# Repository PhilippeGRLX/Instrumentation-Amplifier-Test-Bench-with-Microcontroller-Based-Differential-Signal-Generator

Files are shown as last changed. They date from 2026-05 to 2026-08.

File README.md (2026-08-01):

# Instrumentation Amplifier Test Bench with Microcontroller-Based Differential Signal Generator

#### Implementation of an instrumentation amplififer with PWM-generated differential and common-mode noise source

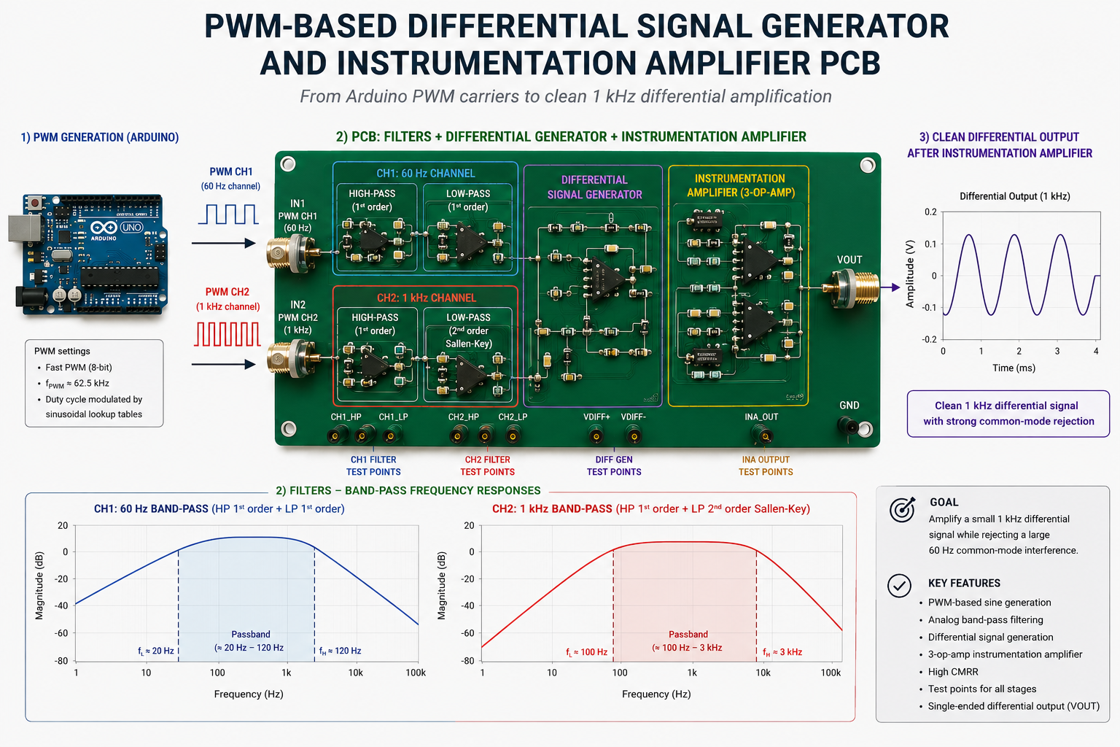
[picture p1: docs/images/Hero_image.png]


## Introduction

The aim of this repository is to help students, hobbyists and engineers build a practical understanding of instrumentation amplifiers (INAs). By exploring their ability to reject common-mode interference while preserving differential signal integrity, the reader will develop an understanding of their key role in signal acquisition and conditioning. The repository also includes a diferrential signal generator designed as a test bench for the instrumentation amplifier. Its design process is well documented for any reader interested in PWM-based signal synthesis, active analog filtering and frequency-domain analysis using oscilloscope measurements and MATLAB.

<p align="center">
<em>
This project is built around the idea that a design is only as valuable as the engineer's ability to validate it experimentally.
</em>
<br>
<sub>Inspired by a discussion with Petr Dvořák on <em>The Amp Hour</em> #669.</sub>
</p>

Throughout this project, the reader will explore:
- Microcontroller-based PWM signal synthesis (Arduino Uno),
- First and second order active filters design for PWM-based sinusoidal signal synthesis,
- Theoretical Frequency domain analysis with Matlab simulations,
- Experimental Frequency domain analysis of the synthesised signals and hardware (oscilloscope),
- Experimental instrumentation amplifier validation.

Project workflow:
1. Generate two PWM-modulated sinusoidal signals using an Arduino.
2. Reconstruct the sinusoidal envelopes through active analog filters.
3. Combine both signals into differential and common-mode components.
4. Characterize the generated signals using oscilloscope measurements and MATLAB.
5. Evaluate the instrumentation amplifier's ability to reject common-mode interference while preserving the differential signal.

> [!IMPORTANT]
> **Why generate sinusoidal test signals?**
>The instrumentation amplifier can be though of as a building block of a signal acquisition circuit. Wires and PCB tracks are susceptible to ambient electromagnetic noise wich deteriorates the useful signal's integrity. The 60 Hz common mode signal used in the test bench is meant to represent the noise induced by the ambient power grid which has a sinusoidal shape. As for the usefull signal, its sinusidal shape is chosen for simplicity, but also because the signal's quality is easy to asses visualy.

> [!Note]
> While the complete PCB files are provided to allow readers to reproduce the project, the primary objective of this repository is educational. Readers are encouraged to adapt, improve, and experiment with the design rather than simply replicate it.

## Table of Contents

- [Introduction](#introduction)

- [System Overview](#system-overview)
  - [Generating Sinusoidal Signals from Filtered PWM Carriers](#generating-sinusoidal-signals-from-filtered-pwm-carriers)
  - [Analog Filter Stages](#analog-filter-stages)
    - [First-Order Active High-Pass Filter](#first-order-active-high-pass-filter)
    - [First-Order Active Low-Pass Filter](#first-order-active-low-pass-filter)
    - [Second-Order Sallen-Key Low-Pass Filter](#second-order-sallen-key-low-pass-filter)
  - [Differential Signal Generator](#differential-signal-generator)
  - [Instrumentation Amplifier](#instrumentation-amplifier)

- [CMRR and Measured Performance](#cmrr-and-measured-performance)

- [Testing the Signal](#testing-the-signal)
  - [Experimental PWM Signal Validation](#experimental-pwm-signal-validation)
  - [Viewing Filtered Sinusoidal Signals](#viewing-filtered-sinusoidal-signals)
  - [Viewing Differential Signals with Common Mode](#viewing-differential-signals-with-common-mode)
  - [Viewing Common-Mode Attenuation](#viewing-common-mode-attenuation)

- [Hardware Implementation](#hardware-implementation)
  - [Breadboard Prototype](#breadboard-prototype)
  - [PCB Design](#pcb-design)
    - [Signal Generator PCB](#signal-generator-pcb)
    - [Instrumentation Amplifier PCB](#instrumentation-amplifier-pcb)
    - [Performance](#performance)

- [Compatibility](#compatibility)
- [Safety](#safety)
- [Resources](#resources)
- [Acknowledgements](#acknowledgements)

## System overview

### Generating sinusoidal signals from filtered PWM carriers

The Arduino could generate a staircase approximation of a sinusoidal waveform directly from the lookup-table (LUT) values. However, the quantization and discrete-time updates inherent to a staircase waveform introduce additional spectral components. Since the objective is to characterize the INA, these imperfections would make it more difficult to distinguish distortion originating from the signal generator from distortion introduced by the instrumentation amplifier under test (See Figure 1).

<p align="center">
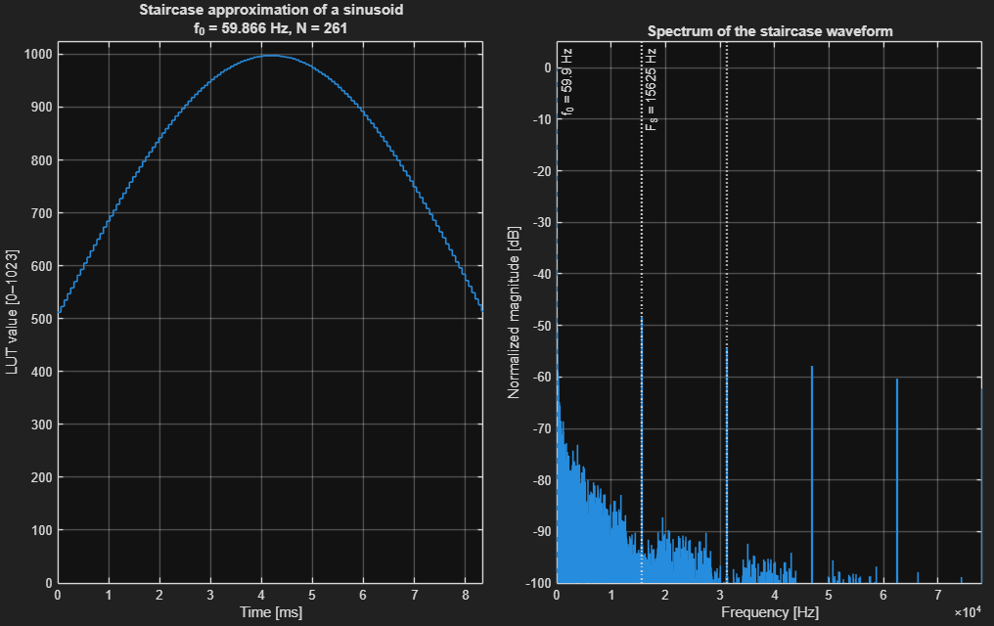
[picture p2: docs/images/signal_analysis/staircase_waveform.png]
  
</p>

<p align="center">
  <em>
    Figure 1. Staircase approximation of the 60 Hz sinusoidal signal
    generated from the lookup-table values and its normalized frequency
    spectrum (right). In addition to the desired fundamental component, the
    discrete update process produces high-frequency spectral images around
    the LUT update frequency.
  </em>
</p>

Instead, the sinusoidal lookup table is used to continuously adjust the duty cycle of a high-frequency PWM carrier. By shifting most of the unwanted spectral content around the PWM carrier frequency, analog reconstruction filters can effectively recover the low-frequency sinusoidal envelope.

The analog reconstruction filters are designed to:
- remove the DC component introduced by the PWM duty-cycle offset,
- preserve the desired sinusoidal envelope,
- attenuate the PWM carrier and its associated sidebands.

The figures below illustrate the signal generation process for the 60 Hz path.

#### Sinusoidal lookup table

The sinusoidal lookup table (LUT) defines the duty-cycle trajectory used to modulate the PWM carrier.

The LUT values are generated offline and embedded in the Arduino firmware through dedicated header files located in the firmware section of this repository. During operation, the microcontroller continuously updates the PWM duty cycle by stepping through the LUT entries.

Although Figure 2 displays a sinusoidal waveform for visualization purposes, no analog sinusoidal voltage is directly generated by the microcontroller. The only signal produced by the Arduino is a variable-duty-cycle PWM waveform whose average value follows the sinusoidal trajectory defined by the LUT.

After analog filtering, the low-frequency sinusoidal envelope is reconstructed while the high-frequency PWM carrier and its associated harmonics are attenuated.
<p align="center">
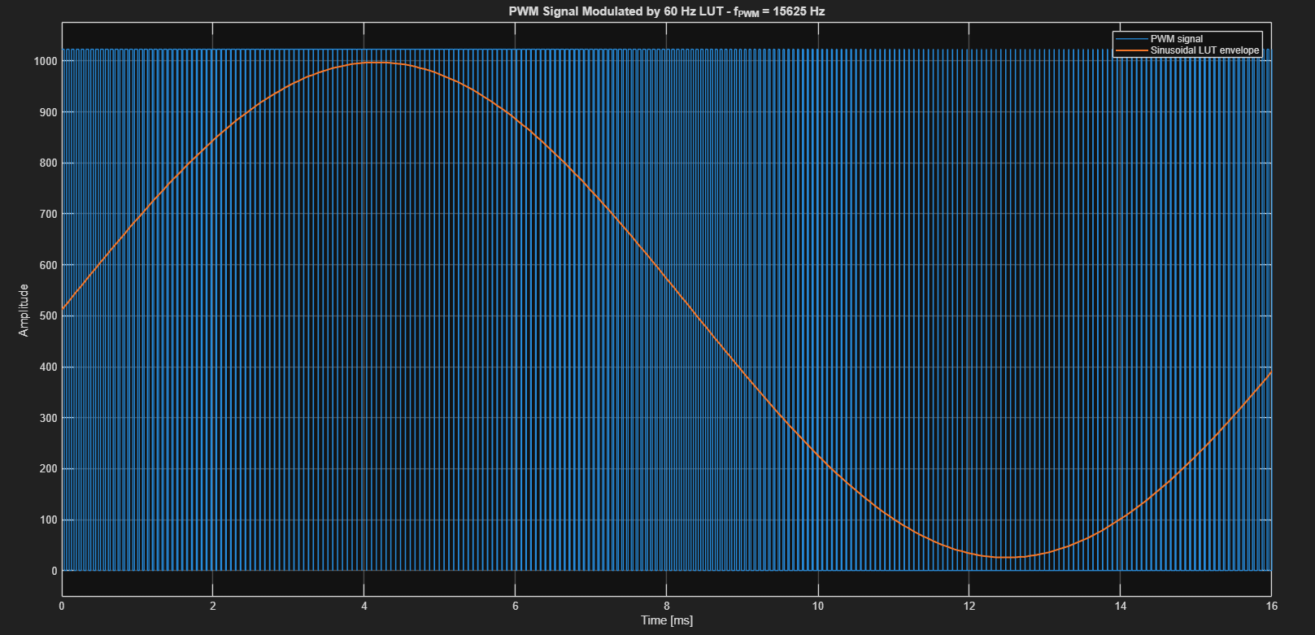
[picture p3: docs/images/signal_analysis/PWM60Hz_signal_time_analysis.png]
  
</p>

<p align="center">
  <em>Figure 2. Time-domain representation of the 60 Hz lookup table and the corresponding PWM waveform.</em>
</p>

#### Frequency-domain analysis

Figure 3 shows the spectrum of the sinusoidal lookup table (LUT), revealing the desired 60 Hz component together with a large DC component resulting from the positive-only PWM duty-cycle range.

Figure 4 shows the spectrum of the corresponding PWM signal. After modulation, the desired 60 Hz component remains dominant, while harmonics introduced by the PWM process remain more than 40 dB below the fundamental component. The PWM carrier, however, also generates high-frequency spectral components around the carrier frequency (see Figure 5). These components are what has to be removed by the analog reconstruction filters, leaving only the desired low-frequency sinusoidal envelope.

<p align="center">
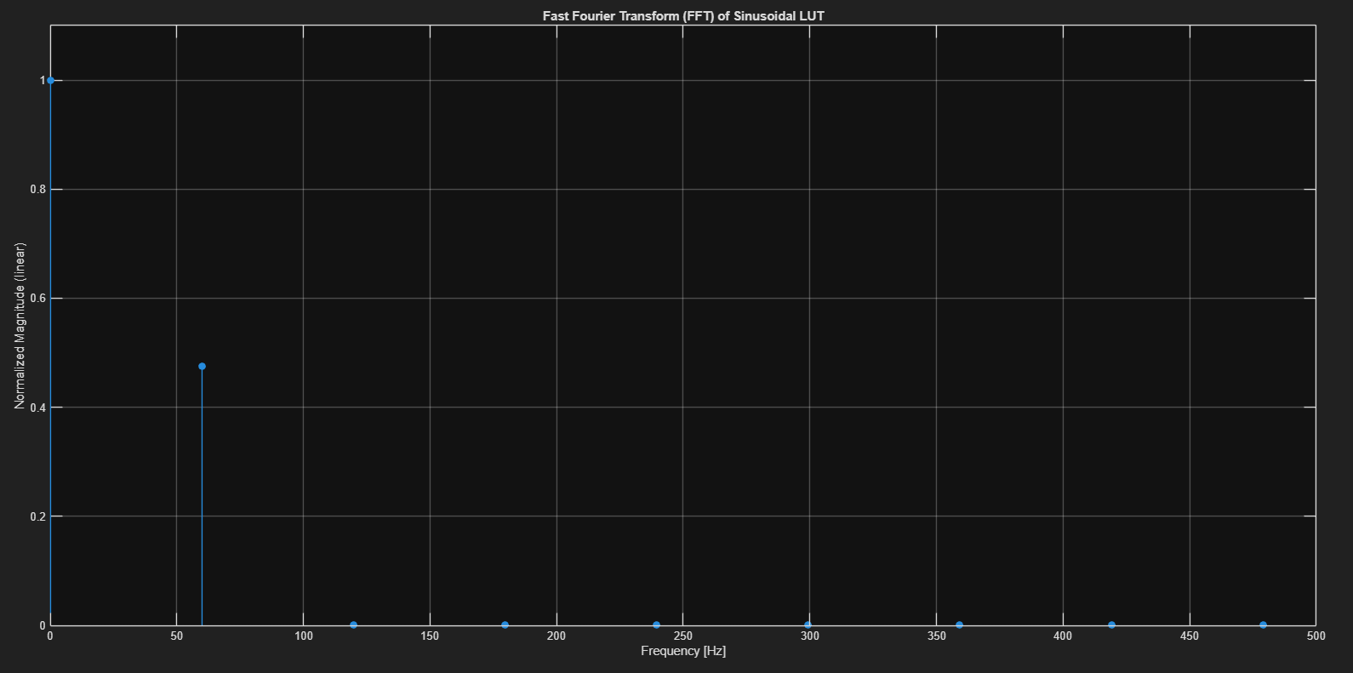
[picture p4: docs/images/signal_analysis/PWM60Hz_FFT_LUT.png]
  
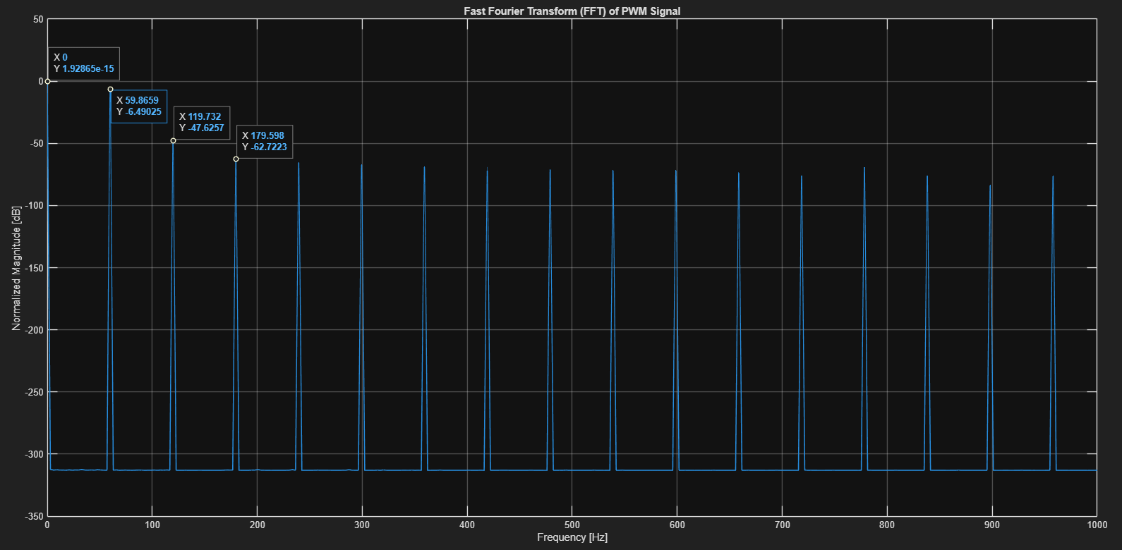
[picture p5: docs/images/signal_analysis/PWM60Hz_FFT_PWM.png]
  
</p>

<p align="center">
  <em>Figure 3. Frequency spectrum of the 60 Hz lookup table.</em><br>
  <em>Figure 4. Frequency spectrum of the LUT-modulated PWM signal(0-1kHz).</em>
</p>

This frequency-domain view highlights two important design objectives:
- remove the DC component introduced by the PWM duty-cycle offset,
- attenuate the remaining harmonic content while preserving the desired 60 Hz sinusoidal component.

#### PWM spectrum and filter response

The figures below show the frequency response of the reconstruction filter superimposed on the spectrum of the LUT-modulated PWM signal.

Figure 5 shows the spectrum of the LUT-modulated PWM signal together with the reconstruction filter response over a wide frequency range. The PWM carrier and its associated sidebands can be observed at high frequencies. The reconstruction filter provides approximately 40 dB of attenuation at the carrier frequency, significantly reducing the PWM switching content.

Figure 6 focuses on the low-frequency region of interest. The DC component is strongly attenuated by the high-pass stage, while the desired 60 Hz component remains within the passband. The figure also highlights the large amplitude difference between the fundamental component and its harmonics, which are more than 40 dB below the 60 Hz signal.

<p align="center">
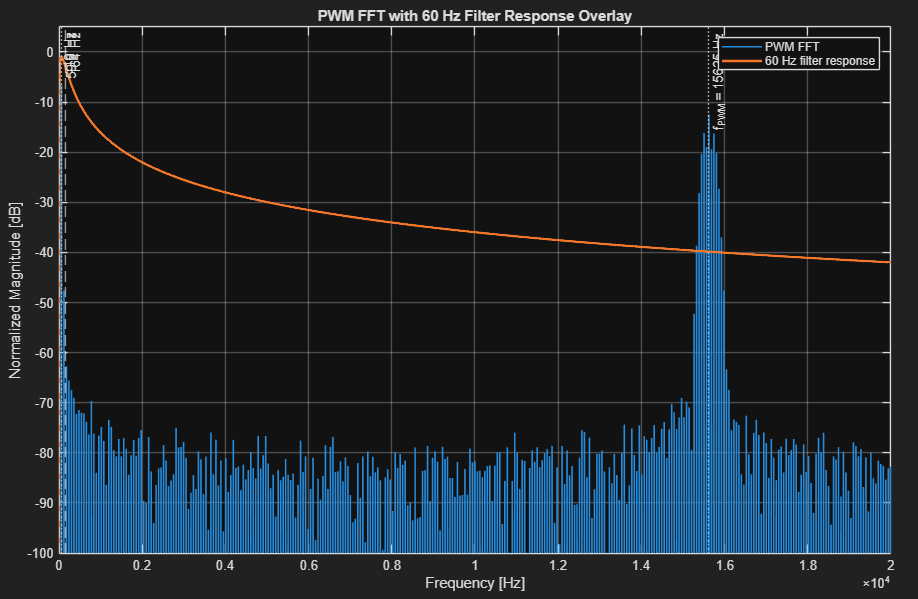
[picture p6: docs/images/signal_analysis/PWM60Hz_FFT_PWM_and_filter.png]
  
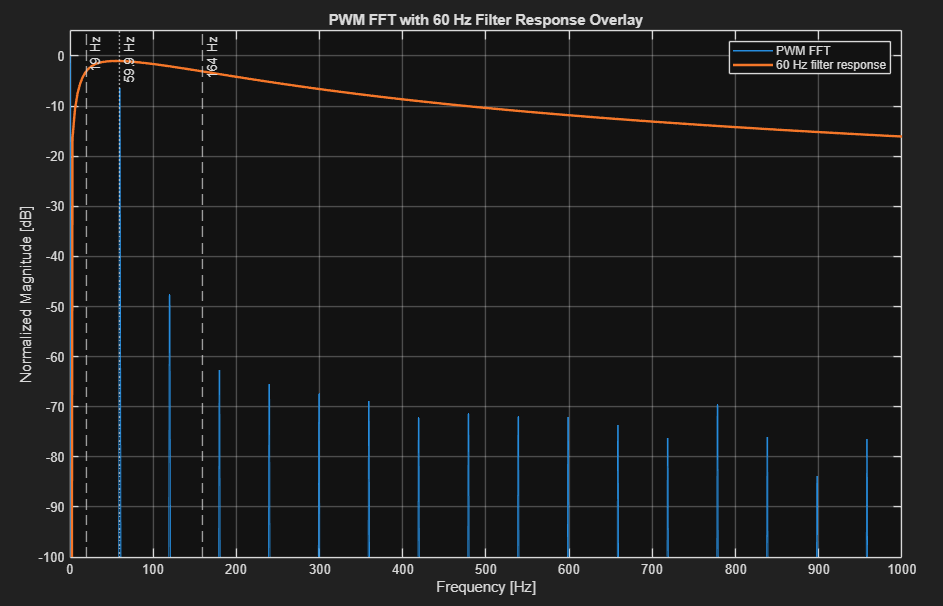
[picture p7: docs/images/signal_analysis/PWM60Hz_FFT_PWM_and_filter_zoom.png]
  
</p>

<p align="center">
  <em>Figure 5. Reconstruction filter response superimposed on the spectrum of the LUT-modulated PWM signal.</em><br>
  <em>Figure 6. Zoomed view of the low-frequency region showing the passband, DC attenuation and harmonic content.</em>
</p>

The resulting 19 Hz – 164 Hz band-pass response preserves the desired 60 Hz sinusoidal component while attenuating both the DC offset and the high-frequency PWM carrier. The origin of these cutoff frequencies is detailed in the Analog Filter Stages section.

This frequency-domain analysis provides valuable insight into the signal reconstruction process before any hardware measurements are performed.

#### 1 kHz signal path

The 1 kHz signal follows the same PWM reconstruction principle as the 60 Hz path. However, generating a 1 kHz sinusoid with the same timer configuration would provide too few duty-cycle updates per period, resulting in visible waveform distortion.

> [!TODO]
> Basic equation for Timer, PWM frequency... justify filter order, stopband needed...

To increase the temporal resolution, the 1 kHz signal is generated using **Timer2** configured for **8-bit Fast PWM** at **62.5 kHz**. Although this reduces the PWM amplitude resolution from 10 bits to 8 bits, the fourfold increase in carrier frequency provides 64 PWM updates per sinusoidal period instead of only 16. This significantly improves the reconstructed waveform while keeping the analog filtering requirements manageable.

The figures below illustrate the frequency-domain behavior of the 1 kHz signal path.

<p align="center">
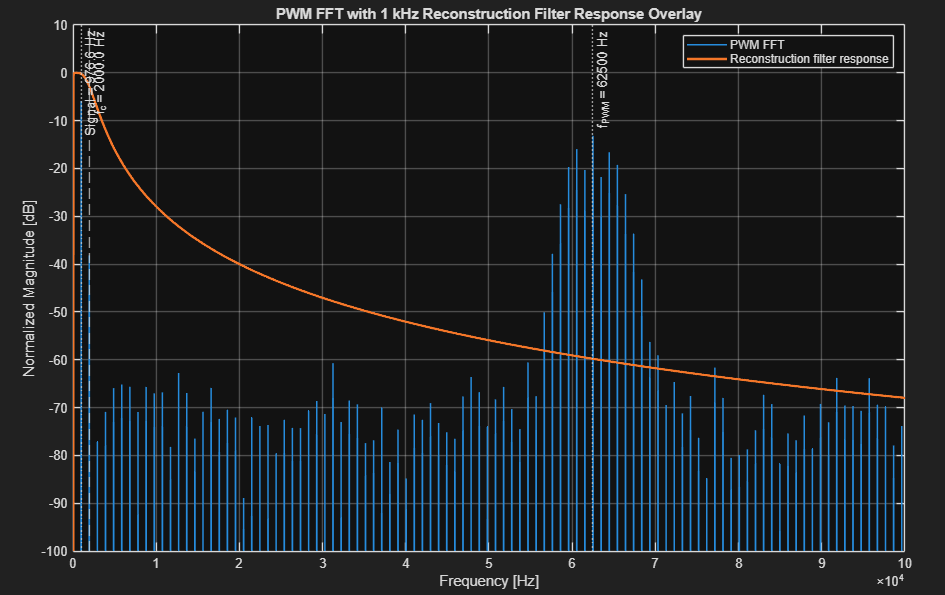
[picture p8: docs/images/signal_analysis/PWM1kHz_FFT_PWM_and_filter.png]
  
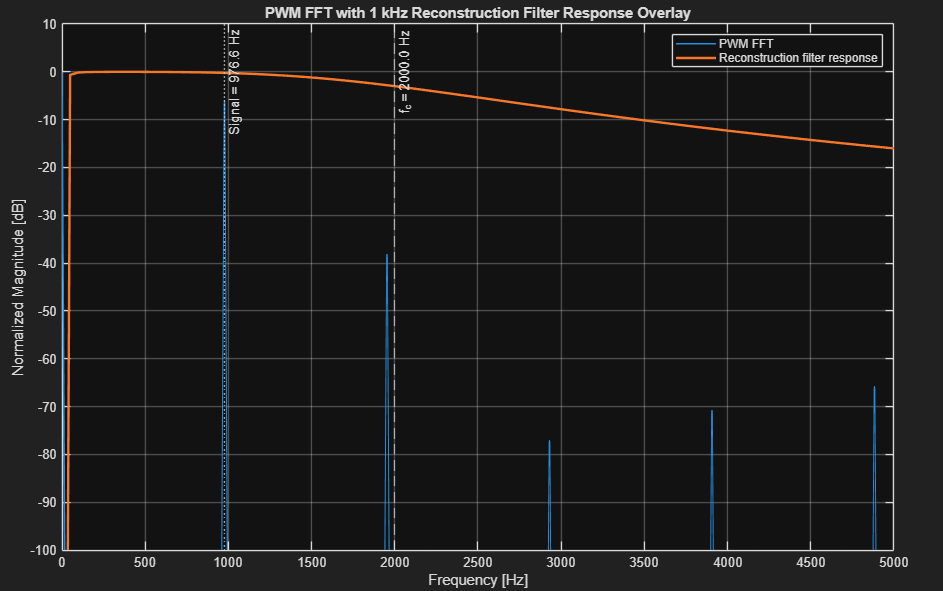
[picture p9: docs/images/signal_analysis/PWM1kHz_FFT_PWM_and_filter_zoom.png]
  
</p>

<p align="center">
  <em>Figure 7. Reconstruction filter response superimposed on the 1 kHz PWM spectrum.</em><br>
  <em>Figure 8. Zoomed view of the 1 kHz passband.</em>
</p>

### Analog Filter Stages
#### First-order active high-pass filter
<p align="center">
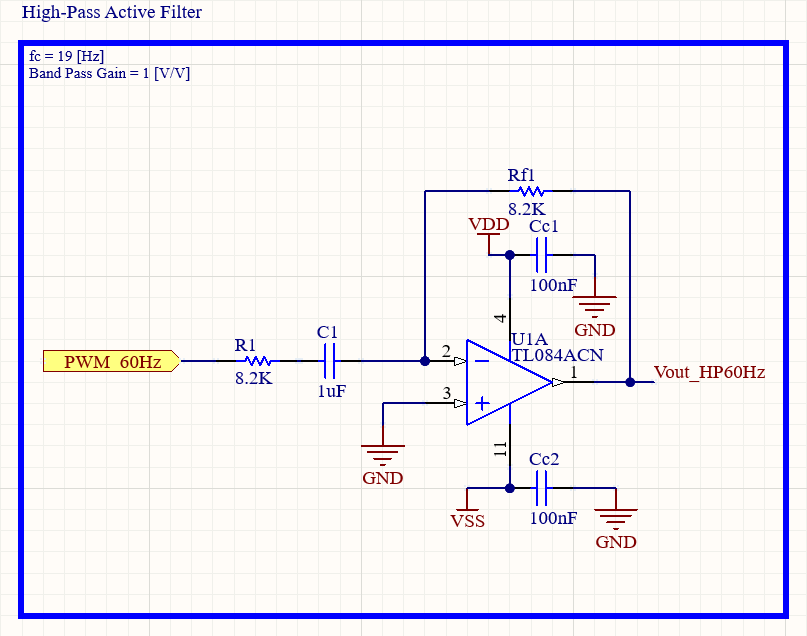
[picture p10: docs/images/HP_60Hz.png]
  
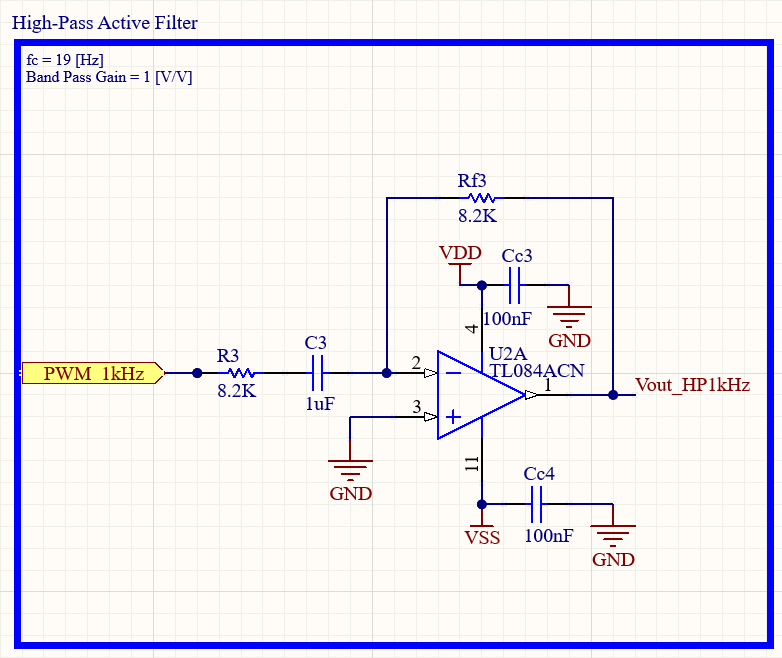
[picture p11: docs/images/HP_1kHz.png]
  
</p>
The first-order active high-pass filters are used to attenuate low-frequency components and remove DC offsets before the low-pass reconstruction stages.

Transfer function:

$$
H(s)=\frac{-R_f C_{in} s}{1+R_{in} C_{in} s}
$$

Cutoff frequency:

$$
f_c=\frac{1}{2\pi R_{in} C_{in}}
$$

| Filter | Design cutoff frequency |
|---|---|
| 60 Hz path | 19 Hz |
| 1 kHz path | 19 Hz |

#### First-order active low-pass filter
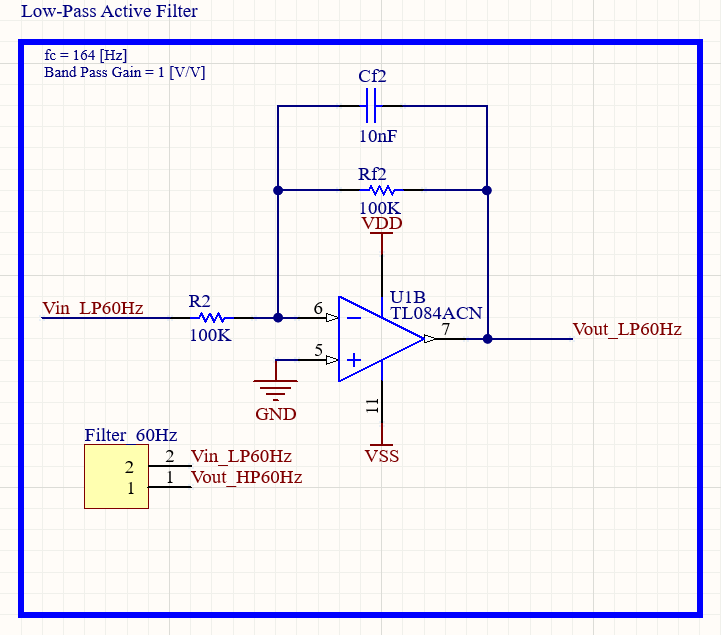
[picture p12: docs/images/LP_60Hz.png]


The first-order active low-pass filter is used to attenuate the high-frequency PWM carrier while preserving the reconstructed sinusoidal envelope.

Transfer function:

$$
H(s)=\frac{-R_f}{R_{in}}\frac{1}{1+R_f C_f s}
$$

Cutoff frequency:

$$
f_c=\frac{1}{2\pi R_f C_f}
$$

| Filter | Design cutoff frequency |
|---|---|
| 60 Hz path | 159 Hz |

#### Second-order Sallen-Key low-pass filter
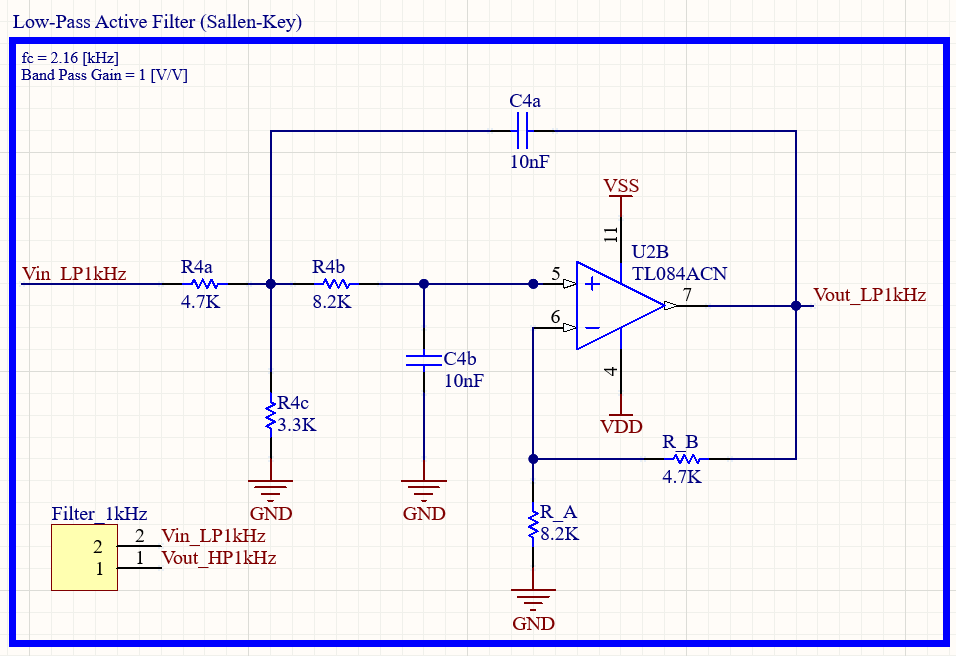
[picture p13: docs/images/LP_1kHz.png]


The second-order Sallen-Key low-pass filter is used to provide stronger attenuation of the high-frequency PWM carrier while preserving the 1 kHz sinusoidal envelope.

Transfer function:

$$
T(s)=
\frac{\frac{K}{R_{4a}R_{4b}C^2}}
{s^2+s\frac{\frac{1}{R_{4a}}+\frac{2-K}{R_{4b}}}{C}
+\frac{1}{R_{4a}R_{4b}C^2}}
$$

where:

$$
K = 1+\frac{R_B}{R_A}
$$

$$
C_{4a}=C_{4b}=C
$$

Cutoff frequency:

$$
f_c=\frac{1}{2\pi\sqrt{R_{4a} R_{4b} C_{4a} C_{4b}}}
$$

| Filter | Design cutoff frequency |
|---|---|
| 1 kHz path | 2 kHz |

### Differential signal generator
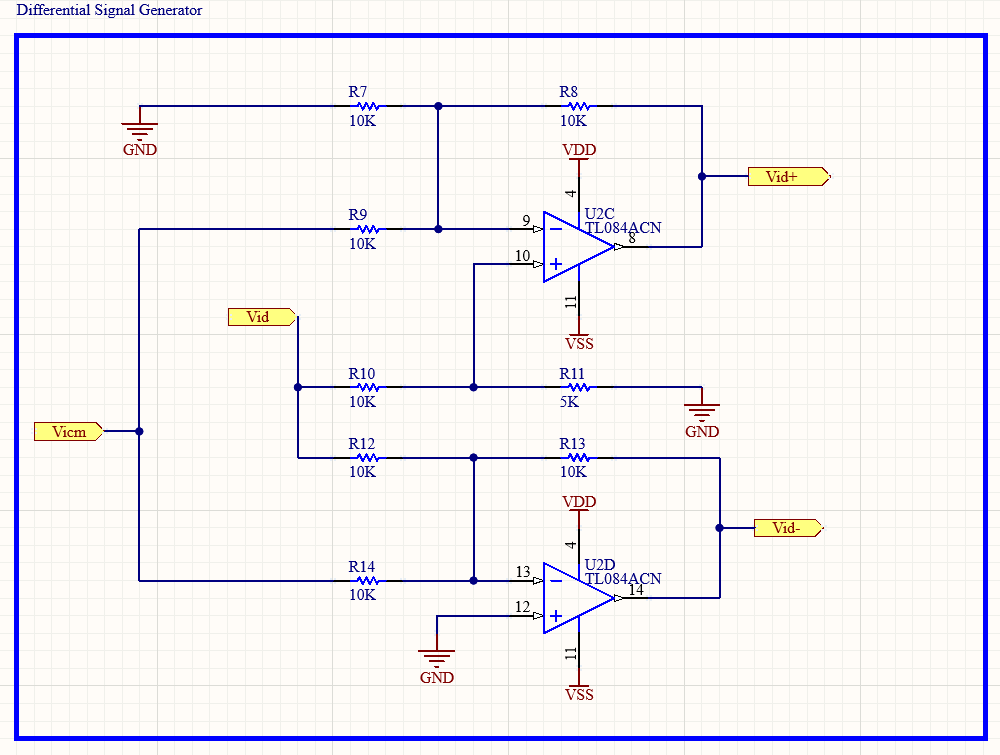
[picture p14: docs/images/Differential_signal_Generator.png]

> [!TIP]
> **Contributions welcome**
>
> This section is still under development.
>
> If you know of good references (books, application notes, university lectures, or papers) covering differential signal generation, common-mode signal injection, feel free to suggest them by opening an issue or submitting a pull request.

> [!TODO]
> Gain for common mode and differential mode experimental validation. PCB

### Instrumentation Amplifier
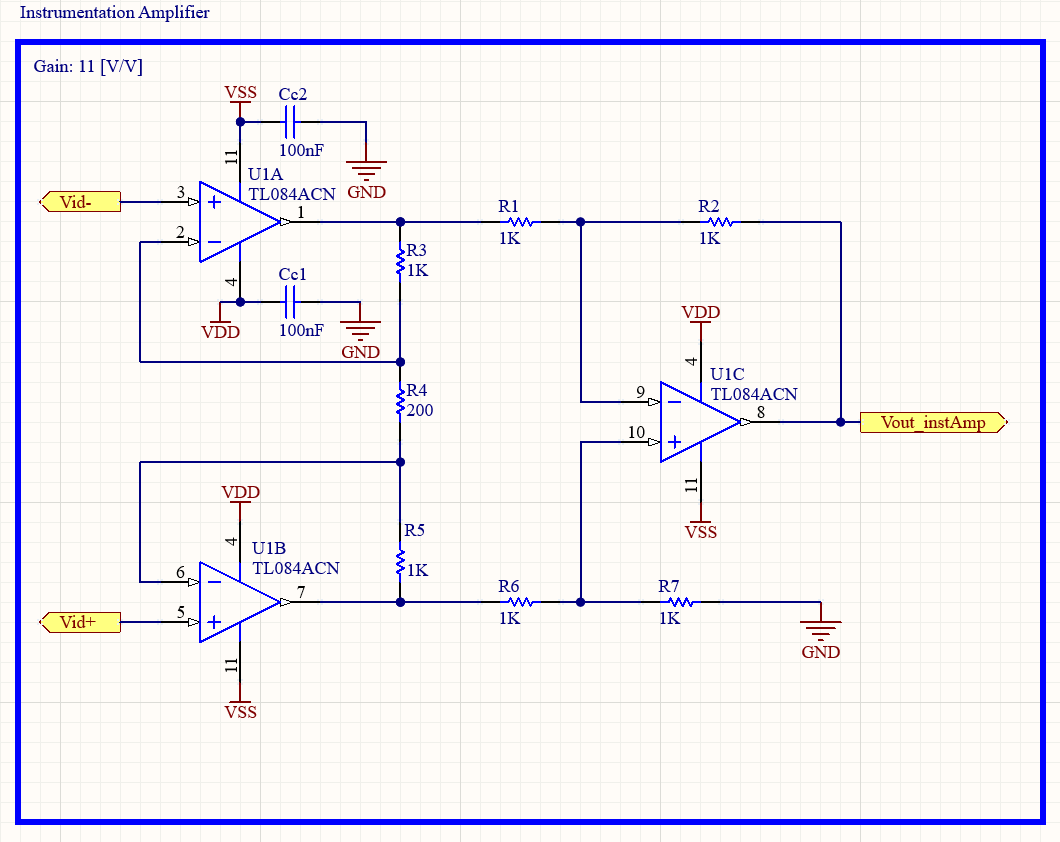
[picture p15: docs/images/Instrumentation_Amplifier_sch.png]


The instrumentation amplifier (INA) is the device under test in this project. Its role is to amplify the differential component of the input signal (1kHz) while rejecting the common-mode interference (60Hz) intentionally injected by the differential signal generator. This makes the test bench suitable for experimentally demonstrating the Common-Mode Rejection Ratio (CMRR), one of the key performance metrics of instrumentation amplifiers.

The circuit is implemented using the classical three-op-amp topology. The first stage provides high input impedance together with programmable differential gain, while the second stage subtracts the two amplified input signals and rejects the common-mode component.

> [!TODO]
> Enrich, stages and roles, effects on common mode and differential mode for each stage.

#### Differential gain

$$
A_d = \frac{R_2}{R_1}\left(1+\frac{R_3}{R_4/2}\right)
$$

#### Common-mode rejection ratio

$$
CMRR=\frac{A_d}{A_{cm}}
$$

or, in decibels,

$$
CMRR_{dB}=20\log_{10}\left(\frac{A_d}{A_{cm}}\right)
$$

**Recommended reference**

Sedra, A. S., Smith, K. C., *Microelectronic Circuits*, 7th Edition,
Section 2.4.2 – *A Superior Circuit: The Instrumentation Amplifier*, p. 82.

## CMRR and Measured Performance
> [!TODO]
> Basic protocol, Vin and Vout figures for V_{cm} an V_{dif}, result table, performance calculation

## Testing the Signal
### Experimental PWM Signal Validation

The PWM carrier signals were experimentally characterized using a Rigol DS1054Z oscilloscope. The acquired waveforms were exported as CSV files and processed in MATLAB to obtain their frequency spectra (Matlab figures are more fun to look at than oscilloscope screenshots).

For the **60 Hz** signal path, the PWM waveform clearly shows the low-frequency sinusoidal envelope modulating the high-frequency PWM carrier. The measured FFT confirms the presence of the desired 60 Hz component together with the PWM carrier, validating both the firmware implementation and the theoretical frequency-domain analysis.

For the **1 kHz** signal path, the corresponding FFT confirms the presence of the desired fundamental component at 976.6 Hz together with the harmonic content introduced by PWM modulation.

<p align="center">
  
  
</p>

<p align="center">
  <em>Figure 9. Measured unfiltered PWM waveforms for the 60 Hz and 1 kHz signal paths.</em>
</p>

<p align="center">
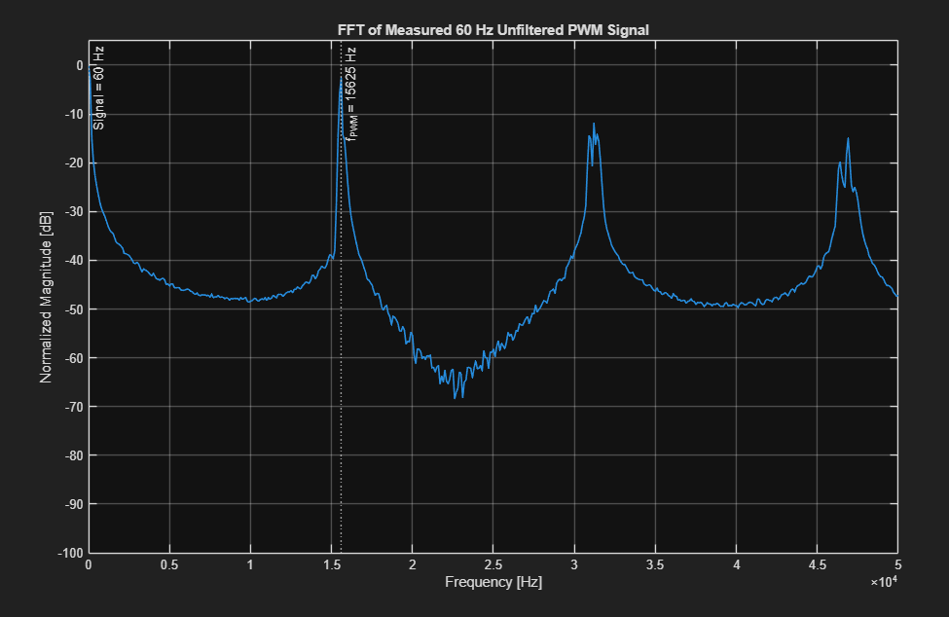
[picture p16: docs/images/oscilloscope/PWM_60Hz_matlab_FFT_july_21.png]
  
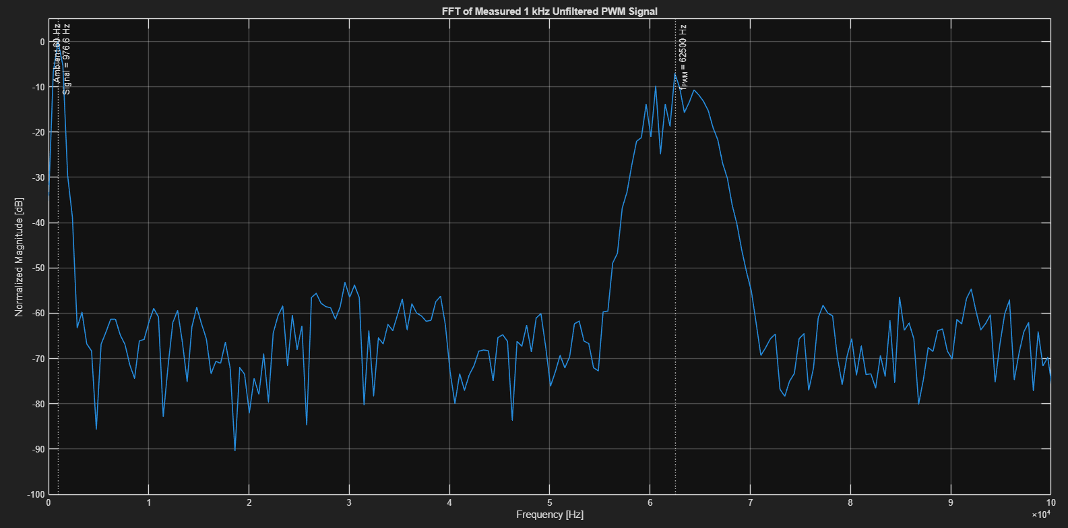
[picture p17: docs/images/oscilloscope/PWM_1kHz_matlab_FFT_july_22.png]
  
</p>

<p align="center">
  <em>Figure 10. MATLAB FFT of the measured PWM waveforms prior to analog reconstruction filtering.</em>
</p>

These measurements validate the PWM generation firmware, the oscilloscope acquisition procedure, and the MATLAB analysis tools before evaluating the analog reconstruction filters.

> [!TODO]
> Refine script for 1kHz FFT, better resolution possible?

### Viewing filtered sinusoidal signals

The two filtered outputs are used as the building blocks for the test signal:
- $V_{icm}$ : 60 Hz sinusoidal common-mode component
- $V_{id}$ : 1 kHz sinusoidal differential-mode component

<p align="center">
  
  
</p>

The initial 1 kHz reconstruction exhibited visible distortion, most likely due to the limited number of PWM duty-cycle updates per sinusoidal period and insufficient attenuation of higher-order harmonics. The issue was resolved by configuring Timer2 for 8-bit Fast PWM operation, which increased the PWM carrier frequency and improved the separation between the desired signal and the carrier, making analog reconstruction significantly more effective.

[!NOTE]
After seeing so many distorted waveforms, seeing a clean 1 kHz sine wave on my oscilloscope for the first time definitely put a smile on my face.

### Viewing differential signals with common mode

The reconstructed 60 Hz common-mode component and the 1 kHz differential component are combined to generate the pair of input signals applied to the instrumentation amplifier, V<sub>id+</sub> and V<sub>id−</sub>.

<p align="center">
  
  
</p>

<p align="center">
  <em>
    Figure 11. Measured outputs of the differential signal generator. Both
    outputs share the same 60 Hz common-mode component, while the 1 kHz
    differential component is applied with a 180° phase shift between
    V<sub>id+</sub> and V<sub>id−</sub>. The full acquisition is shown on the left,
    while the zoomed view on the right highlights the differential voltage
    between the two outputs.
  </em>
</p>

### Viewing common-mode attenuation
> [!TODO]
> ScopeShot needed of differential signal with common mode... and Vout after the INA. To test on PCB!

## Hardware Implementation
### Breadboard Prototype

The complete signal generator was first assembled and validated on a solderless breadboard before the PCB was designed. This prototype allowed the analog filters and differential signal generation to be experimentally verified while providing a convenient platform for debugging and iterative improvements.

The breadboard implementation also facilitated oscilloscope measurements used throughout this repository to validate the theoretical analysis and guide the final hardware design.

<p align="center">
  
</p>

<p align="center">
  <em>
    Figure 12. Breadboard implementation of the differential signal generator
    used to validate the PWM reconstruction filters and the generated
    differential and common-mode signals prior to PCB fabrication.
  </em>
</p>

### PCB Design
> [!TODO]
> Order, build, test and Photoshoot!

#### Signal Generator PCB
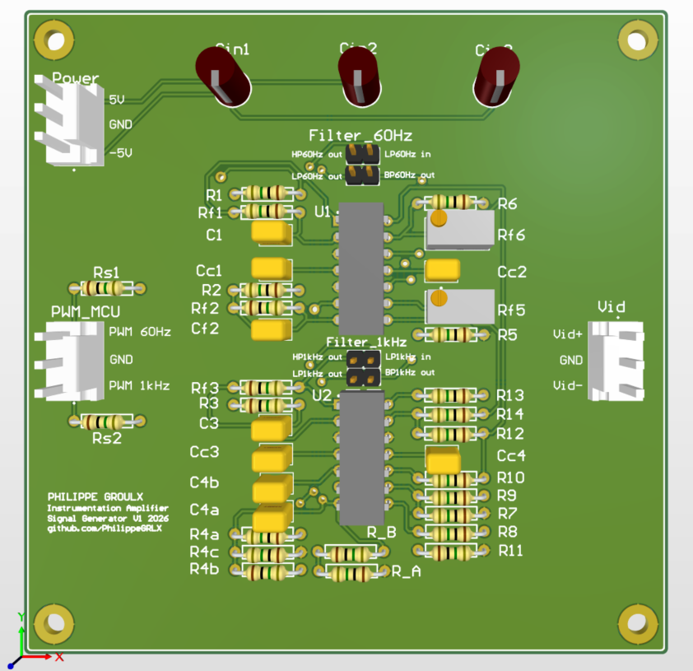
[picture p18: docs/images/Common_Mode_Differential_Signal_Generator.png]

#### Instrumentation Amplifier PCB
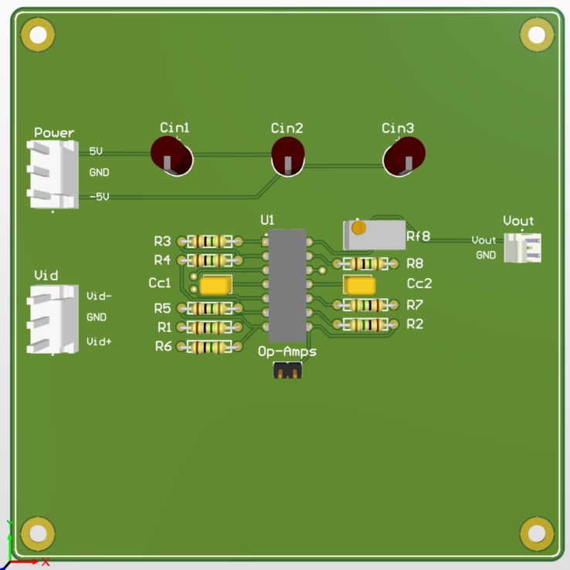
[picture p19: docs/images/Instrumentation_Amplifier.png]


#### Performance
> [!TODO]
> Clean Table with Instrumentation Amplifier performance Acm, Ad, CMMR. To do with PCB!

## Compatibility
### Software

| Software | Version |
|---|---|
| Altium Designer | 26.5.1 (or later) |
| MATLAB | R2025b (or later) |
| Arduino IDE | 2.3.10 |
| Git | Any recent version |

### Hardware

| Item | Notes |
|---|---|
| Arduino Uno | ATmega328P, 16 MHz |
| Dual power supply | ±5 V |
| Oscilloscope | Any ≥20 MHz bandwidth |

## Safety

This project is intended for educational and laboratory use.

The signal generator and instrumentation amplifier operate from a **±5 V dual power supply**, making the circuit relatively safe to handle. Nevertheless, good laboratory practices should always be followed.

- Verify all wiring before powering the circuit.
- Double-check the polarity of the dual supply rails.
- Never exceed the absolute maximum ratings of the integrated circuits.
- Ensure that all instruments share a common reference when making oscilloscope measurements.
- Disconnect power before modifying the circuit or replacing components.

This repository does not involve mains voltages. The 60 Hz common-mode signal is **synthetically generated** and is **not** connected to the electrical power grid.

The authors assume no responsibility for damage to equipment or personal injury resulting from the misuse or modification of this design.

## Resources

Related instrumentation amplifier projects:

- [Laboratory Instrumentation Amplifier with 16-bit 1 MSPS ADC](https://github.com/drmcnelson/Laboratory-Instrumentation-Amplifier-with-16bit-1MSPS-ADC)
- [Design and Implementation of Instrumentation amplifier](https://github.com/GanderlaChaithanya/Design_and_Implementation_of_Instrumentation_amplifier)

## Acknowledgements

Parts of this project were inspired by laboratory material and concepts
developed for the course:

**GEL-3000 - Électronique des composants intégrés (Université Laval)**

Special thanks to:
- Prof. Benoit Gosselin
- Michelle Janusz
- Sébastien Rigaut
- Antoine Lefloïc

for their contributions to the original laboratory framework and educational material.

This repository extends and adapts those concepts into a standalone experimental
instrumentation amplifier and signal-generation test bench.

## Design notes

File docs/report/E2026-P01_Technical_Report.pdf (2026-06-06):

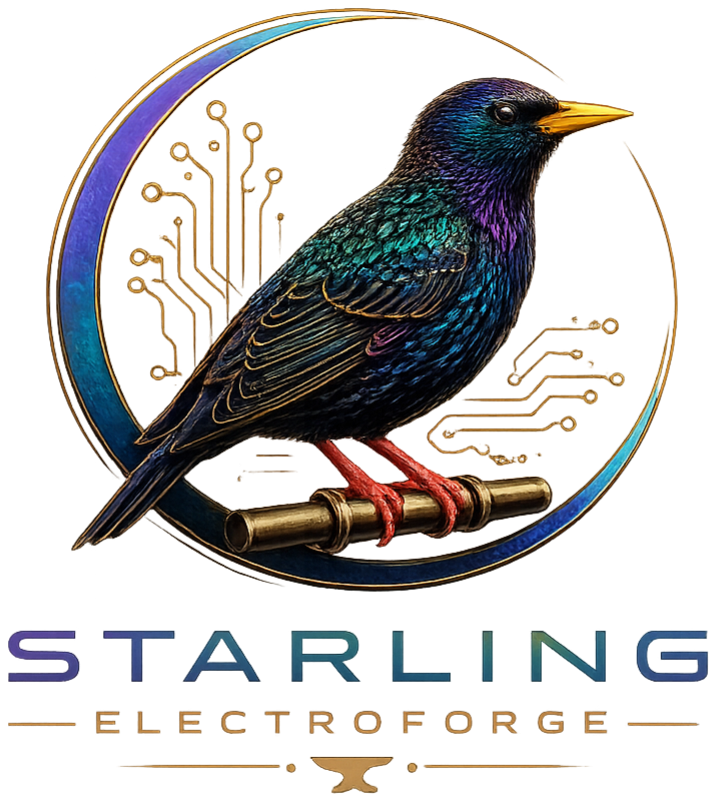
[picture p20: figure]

Starling ElectroForge

Research and Development Division

Design Portfolio Series

E2026-P01 Technical Report

# Instrumentation Amplifier Test Bench with Microcontroller-Based Differential Signal Generator

Author:

Philippe Groulx-Létourneau

Status:
Released
Revision A

June 6, 2026

1 Design Requirements and Specifications

## 1 Design Requirements and Specifications

This project aims to design, build, and validate an instrumentation amplifier test bench with a microcontroller-based differential signal generator. The work is divided into six main deliverables.

### 1.1 Microcontroller-Based Differential Signal Generator

- Generate a 60 Hz sinusoidal signal using filtered PWM output from an Arduino Uno.
- Generate a 1 kHz sinusoidal signal using filtered PWM output from an Arduino Uno.
- Combine both sinusoidal signals to produce a noisy differential signal.
- Build and validate the circuit on a breadboard.
- Validate the quality of the sinusoidal output signals.

### 1.2 Three-Op-Amp Instrumentation Amplifier

- Design a three-op-amp instrumentation amplifier circuit.
- Calculate the required passive component values using 5% tolerance components.
- Select appropriate operational amplifiers.
- Build the circuit on a breadboard.
- Validate common-mode rejection performance through CMRR measurements.

### 1.3 Breadboard Characterization

- Measure the main circuit parameters of the breadboard implementation, including cutoff frequencies and gains.
- Measure the actual values of the passive components used in the noisy signal generator and instrumentation amplifier.
- Refine component values through iterative SPICE simulation and breadboard validation to achieve the desired performance.
- Measure the common-mode rejection ratio (CMRR) using 5% tolerance components by determining both differential gain and common-mode gain.
Research and Development Division | 1

### 1.4 GitHub Repository and Documentation

- Create and maintain a GitHub repository for the project.
- Write a complete README file.
- Include Altium schematics.
- Include a design report documenting calculations, implementation, and validation results.
- Include visual support to illustrate signals at each filtering/amplifing stage.
- Include oscilloscope captures illustrating signal quality and behavior at each stage of the system.

### 1.5 Performance Improvement with Precision Components

- Replace critical passive components with 1% precision parts.
- Measure the common-mode rejection ratio (CMRR) using 1% components.
- Compare the results obtained with 5% and 1% resistor tolerances.

### 1.6 PCB Implementation

- Design and manufacture two 100 mm × 100 mm PCBs:

– one PCB for the signal generator;

– one PCB for the instrumentation amplifier.

- Add test points to validate/study the behavior of each filter and amplifier stage.
- Include proper connectors and terminal labels.

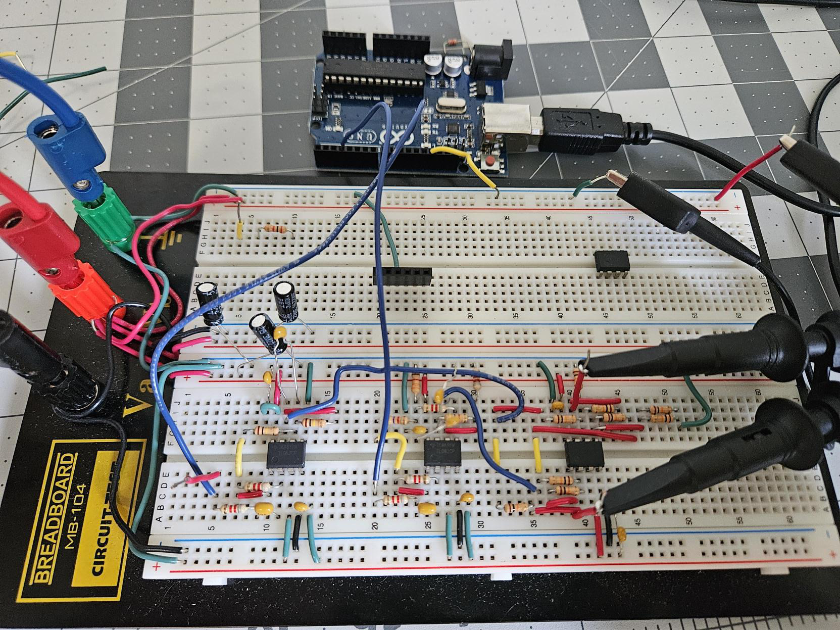
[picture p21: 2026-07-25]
docs/images/BreadBoard_july_25.jpg

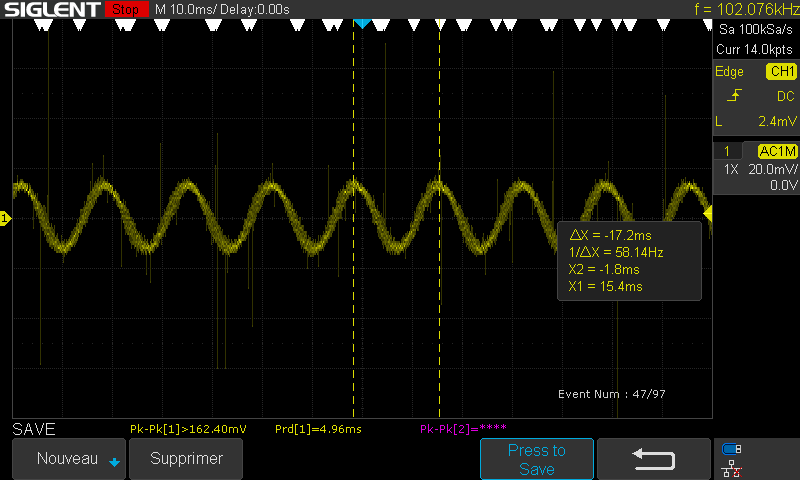
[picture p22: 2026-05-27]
docs/images/oscilloscope/Vicm_mai_25_2026.png

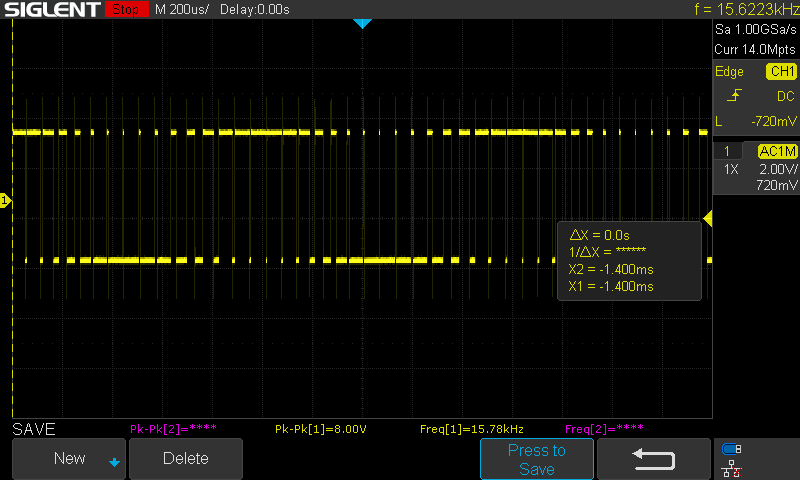
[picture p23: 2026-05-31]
docs/images/oscilloscope/PWM_1kHz_mai_30_2026.png

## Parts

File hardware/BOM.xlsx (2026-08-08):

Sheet: Sheet1
DESIGNATOR | QTY | ORDER | MANUF. PART No | MANUFACTURER | PACKAGE | DESCRIPTION | MAGASIN | Link | Footprint, Symbol and 33d Model (link)
Instrumentation amplifier
CC1, CC2 | 2 | 10 |  |  |  | cap céramique, 100 nF
R1, R2, R3, R5, R6, R7 | 6 | 50 |  |  |  | Res 1 kOhm, 5%
R4 | 1 | 25 |  |  |  | Res 200 Ohm, 5%
U1 | 1 | 10 |  |  |  | TL084CN
INA Non-Inverter
R8 | 1 |  |  |  |  | Res 1 kOhm, 5%
Rf8 | 1 | 5 |  |  |  | Res trimmer 100kOhm
"INA, Non-inv" | 1 | 50 |  |  |  | Jumper
INA Connectors
"Power" | 1 | 20 |  |  |  | Header 3pin
Cin1, Cin2, Cin3 | 2 | 20 |  |  |  | capacitor, polarized, 10uF
"Vid" |  |  |  |  |  | Header 3pin
"Vout" |  |  |  |  |  | Header 2pin
Differential Signal Generator
Sig. Gen. - Connectors
Power |  |  |  |  |  | Header 3pin
PWM_MCU |  |  |  |  |  | Header 3pin
Vid |  |  |  |  |  | Header 3pin
Cin1, Cin2, Cin3 |  |  |  |  |  | capacitor, polarized, 10uF
Rs1, Rs2 | 2 | 25 |  |  |  | Res 220 Ohm, 5%
60Hz Path - Filters
R1, Rfl | 2 | 25 |  |  |  | Res 8.2 kOhm, 5%
C1 | 1 | 10 |  |  |  | 1 uF, Capacitor, ceramic, 5%
U1 (INA) |  |  |  |  |  | TL084CN
Cc1, Cc2 |  |  |  |  |  | cap céramique, 100 nF
Filter 60Hz |  |  |  |  |  | Jumper
R2, Rf2 | 2 | 25 |  |  |  | Res 100 kOhm, 5%
Cf2 | 1 | 10 |  |  |  | 10 nF, Capacitor, ceramic, 5%
60Hz Path - Non-inverter
R5 | 1 | 50 |  |  |  | Res 10 kOhm, 5%
Rf5 |  |  |  |  |  | Res trimmer 100kOhm
Filter 60Hz2 |  |  |  |  |  | Jumper
1kHz Path - Filters
R3, Rf3 |  |  |  |  |  | Res 8.2 kOhm, 5%
C3 |  |  |  |  |  | 1 uF, Capacitor, ceramic, 5%
U2 (INA) |  |  |  |  |  | TL084CN
Cc3, Cc4 |  |  |  |  |  | cap céramique, 100 nF
R4a, R_B | 2 | 25 |  |  |  | Res 4.7 kOhm, 5%
R4b, R_A | 2 |  |  |  |  | Res 8.2 kOhm, 5%
R4c | 1 | 25 |  |  |  | Res 3.3 kOhm, 5%
C4a, C4b | 2 |  |  |  |  | cap céramique, 10 nF
Filter 1kHz |  |  |  |  |  | Jumper
1kHz Path - Non-inverter
R6 |  |  |  |  |  | Res 10 kOhm, 5%
Rf6 |  |  |  |  |  | Res trimmer 100kOhm
Filter 1kHz_2 |  |  |  |  |  | Jumper
Differential Signal Generator - Signal Generator
R7, R8, R9, R10, R12, R13, R14 |  |  |  |  |  | Res 10 kOhm, 5%
R11 | 1 | 10 |  |  |  | Res 5 kOhm( 300Ohm), 5% (4.7k + 300 Ohm)
https://www.digikey.ca/short/h98hvh78

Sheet: Sheet2
DigiKey - Shopping Cart
Index | Quantity | Part Number | Manufacturer Part Number | Description | Customer Reference | Available | Backorder | Unit Price | Extended Price USD
1 | 50 | CF14JT1K00CT-ND | CF14JT1K00 | RES 1K OHM 5% 1/4W AXIAL |  | 50 | 0 | 0.0198 | 0.99
2 | 25 | CF14JT200RCT-ND | CF14JT200R | RES 200 OHM 5% 1/4W AXIAL |  | 25 | 0 | 0.0228 | 0.57
3 | 50 | S9337-ND | QPC02SXGN-RC | CONN JUMPER SHORTING .100" GOLD |  | 50 | 0 | 0.025 | 1.25
4 | 20 | A19890-ND | 640445-3 | CONN HEADER VERT 3POS 3.96MM |  | 20 | 0 | 0.21 | 4.2
5 | 20 | 1189-2322-ND | 50YXJ10M5X11 | CAP ALUM 10UF 20% 50V RADIAL TH |  | 20 | 0 | 0.185 | 3.7
6 | 25 | CF14JT220RCT-ND | CF14JT220R | RES 220 OHM 5% 1/4W AXIAL |  | 25 | 0 | 0.0228 | 0.57
7 | 10 | 399-C320C105K5N5TA-ND | C320C105K5N5TA | CAP CER 1UF 50V X8L RADIAL |  | 10 | 0 | 0.537 | 5.37
8 | 10 | 399-4150-ND | C315C103M5U5TA | CAP CER 10000PF 50V Z5U RADIAL |  | 10 | 0 | 0.229 | 2.29
9 | 50 | CF14JT10K0CT-ND | CF14JT10K0 | RES 10K OHM 5% 1/4W AXIAL |  | 50 | 0 | 0.0198 | 0.99
10 | 25 | CF14JT4K70CT-ND | CF14JT4K70 | RES 4.7K OHM 5% 1/4W AXIAL |  | 25 | 0 | 0.0228 | 0.57
11 | 25 | CF14JT3K30CT-ND | CF14JT3K30 | RES 3.3K OHM 5% 1/4W AXIAL |  | 25 | 0 | 0.0228 | 0.57
12 | 10 | CF14JT300RCT-ND | CF14JT300R | RES 300 OHM 5% 1/4W AXIAL |  | 10 | 0 | 0.027 | 0.27
13 | 10 | 399-4151-ND | C315C104M5U5TA | CAP CER 0.1UF 50V Z5U RADIAL |  | 10 | 0 | 0.271 | 2.71
14 | 10 | 296-1784-5-ND | TL084CN | IC OPAMP JFET 4 CIRCUIT 14DIP |  | 10 | 0 | 0.725 | 7.25

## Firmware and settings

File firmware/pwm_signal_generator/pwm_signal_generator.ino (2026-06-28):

/*
------------------------------------------------------------------------------
Project:
Instrumentation Amplifier Test Bench with Microcontroller-Based Differential
Signal Generator

File:
pwm_signal_generator.ino

Description:
This firmware generates two PWM-modulated sinusoidal signals using hardware
timers on the Arduino Uno.

The 60 Hz signal path uses Timer1 in 10-bit Fast PWM mode. This preserves the
original higher duty-cycle resolution used for the common-mode signal.

The 1 kHz signal path uses Timer2 in 8-bit Fast PWM mode. This increases the
PWM carrier frequency to approximately 62.5 kHz, providing more lookup-table
updates per sine period and improving analog reconstruction of the 1 kHz signal.

The PWM duty cycles are updated from lookup tables (LUTs). After analog
filtering, the average value of each PWM waveform is reconstructed as a
low-frequency sinusoidal envelope.

Generated signals:
- ~60 Hz sinusoidal envelope on pin 9  (OC1A / Timer1)
- ~1 kHz sinusoidal envelope on pin 3  (OC2B / Timer2)

Hardware:
- Arduino Uno
- Timer1 Fast PWM 10-bit mode for the 60 Hz path
- Timer2 Fast PWM 8-bit mode for the 1 kHz path
- PWM outputs:
    Pin 9 -> 60 Hz path
    Pin 3 -> 1 kHz path

Author:
Philippe Groulx-Letourneau

Repository:
github.com/PhilippeGRLX/Instrumentation-Amplifier-Test-Bench-with-Microcontroller-Based-Differential-Signal-Generator

------------------------------------------------------------------------------
Acknowledgements

Parts of the PWM generation framework used in this project were adapted
from laboratory material developed for the course:

"GEL-3000 - Électronique des composants intégrés (Université Laval)"

Contributors to the original laboratory material:
- Prof. Benoit Gosselin
- Sébastien Rigaut
- Michelle Janusz
- Antoine Lefloïc

The firmware has since been modified and extended for this project.
------------------------------------------------------------------------------
*/




// -----------------------------------------------------------------------------
// Setup
// -----------------------------------------------------------------------------

// -----------------------------------------------------------------------------
// Lookup Tables
// -----------------------------------------------------------------------------

#include "lookup_tables/f60Hz.h"
#include "lookup_tables/f1kHz.h"

// -----------------------------------------------------------------------------
// PWM Output Pins
// -----------------------------------------------------------------------------

#define PWM_60HZ_PIN 9   // OC1A - Timer1
#define PWM_1KHZ_PIN 3   // OC2B - Timer2

void setup() {
  pinMode(PWM_60HZ_PIN, OUTPUT);
  pinMode(PWM_1KHZ_PIN, OUTPUT);
  pinMode(LED_BUILTIN, OUTPUT);

  noInterrupts();

// -----------------------------------------------------------------------------
// Timer1 Configuration
// Fast PWM 10-bit mode
// PWM frequency ≈ 15.625 kHz
// -----------------------------------------------------------------------------

  // Fast PWM 10-bit, Timer1, prescaler = 1
  TCCR1A =
    (1 << COM1A1) |  // Enable PWM on pin 9
    (1 << WGM11)  |
    (1 << WGM10);

  TCCR1B =
    (1 << WGM12) |
    (1 << CS10);     // Prescaler = 1

  TIMSK1 =
    (1 << TOIE1);    // Overflow interrupt ON
// -----------------------------------------------------------------------------
// Timer2 Configuration
// Fast PWM 8-bit mode
// PWM frequency = 16 MHz / 256 = 62.5 kHz
// Pin 3 = OC2B
// -----------------------------------------------------------------------------
TCCR2A =
  (1 << COM2B1) |  // Enable PWM on pin 3
  (1 << WGM21)  |
  (1 << WGM20);

TCCR2B =
  (1 << CS20);     // Prescaler = 1

TIMSK2 =
  (1 << TOIE2);    // Timer2 overflow interrupt ON



  interrupts();
}

// -----------------------------------------------------------------------------
// Main Loop
// -----------------------------------------------------------------------------

void loop() {}

// -----------------------------------------------------------------------------
// Timer1 Overflow Interrupt
// Updates the 60 Hz PWM duty cycle
// -----------------------------------------------------------------------------

ISR(TIMER1_OVF_vect) {
  static uint16_t i60 = 0;

  OCR1A = LUT_f60Hz[i60];   // Pin 9

  i60++;
  if (i60 >= N_SINE_60HZ) i60 = 0;
}

// -----------------------------------------------------------------------------
// Timer2 Overflow Interrupt
// Updates the 1 kHz PWM duty cycle
// -----------------------------------------------------------------------------

ISR(TIMER2_OVF_vect) {
  static uint16_t i1k = 0;

  OCR2B = LUT_f1kHz[i1k];   // Pin 3

  i1k++;
  if (i1k >= N_SINE_1KHZ) i1k = 0;
}

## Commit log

2026-05-07 Structure de projet initiale.
2026-05-07 Ajout Altium generateur PWM 60Hz
    [Amplificateur_instrumentation_E2026.PrjPcb, Filtres_PWM_Generateur_Bruit.SchDoc, Generateur_signal.PcbLib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]
2026-05-07 MAJ filtre, mods mineures
    [Filtre_PWM1kHz.SchDoc, Filtre_PWM60Hz.SchDoc, signal-generator.PrjPcb]
2026-05-12 Circuits testés lab, validés!
    [Filtre_PWM1kHz.SchDoc, Filtre_PWM60Hz.SchDoc, signal-generator.PrjPcb]
2026-05-12 Ajout generateur signal différentiel
    [Differential_Noise_Generator.SchDoc, Filtre_PWM1kHz.SchDoc, Filtre_PWM60Hz.SchDoc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]
2026-05-13 Ajout ports
    [Differential_Noise_Generator.SchDoc, Filtre_PWM1kHz.SchDoc, Filtre_PWM60Hz.SchDoc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]
2026-05-15 Layout fait version1
    [Generator_main.SchDoc, Signal_Generator.PcbDoc, signal-generator.PrjPcb]
2026-05-15 Layout fait, 3D Models en cours
    [Generator_main.SchDoc, Signal_Generator.PcbDoc, Signal_Generator.PcbLib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]
2026-05-18 Routing fait, mta placés, DRC good
    [Generator_main.SchDoc, Signal_Generator.PcbDoc, Signal_Generator.PcbLib]
2026-05-21 Ajout PCB Gen
2026-05-21 Noms schematic sheets
    [Differential_Signal_Generator.SchDoc, Filters_PWM1kHz.SchDoc, Filters_PWM60Hz.SchDoc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]
2026-05-21 Ajout ampli instrumentation
    [Instrumentation-Amplifier.PcbDoc, instrumentation-amplifier.PrjPcb, instrumentation-amplifier.SchDoc]
2026-05-22 Ajout non-inverseur, ampli instru testé
    [instrumentation-amplifier.PrjPcb, instrumentation-amplifier.SchDoc, signal-generator.PrjPcb]
2026-05-22 Instrumentation Amplifier with connectors, done
    [instrumentation-amplifier.PrjPcb, instrumentation-amplifier.SchDoc]
2026-05-22 InstAmp debut layout
    [Instrumentation-Amplifier.PcbDoc, instrumentation-amplifier.PrjPcb, instrumentation-amplifier.SchDoc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]
2026-05-23 PCB Instrumentation Amplifier Done
    [Instrumentation-Amplifier.PcbDoc, instrumentation-amplifier.SchDoc]
2026-05-23 Instrumentation Amplifier PCB figure
2026-05-23 InstAmp silkscreen
    [Instrumentation-Amplifier.PcbDoc, instrumentation-amplifier.PrjPcb]
2026-05-23 filter stages figures
2026-05-24 Arduino gen V1 done, not tested
2026-05-25 Update figures and ReadMe
    [Differential_Signal_Generator.SchDoc, Filters_PWM1kHz.SchDoc, Filters_PWM60Hz.SchDoc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]
2026-05-27 lab results filtered sin waves, update REadme
    [instrumentation-amplifier.SchDoc]
2026-05-31 PWM signals on scope
2026-06-23 Update Readme, fix LUTs
    [pwm_signal_generator.ino]
2026-06-23 Update ReadMe PWM 60Hz, done
2026-06-28 Update 60Hz Filters figures
    [Filters_PWM60Hz.SchDoc, Signal_Generator.PcbDoc]
2026-06-28 Update 60Hz figures and malab script
    [Filters_PWM60Hz.SchDoc]
2026-06-28 Arduino firmware update and 1kHz rework
    [pwm_signal_generator.ino]
2026-06-29 1kHz Progress on matlab, LUT, Arduino script
2026-06-30 Update ReadMe 60Hz
2026-06-30 1kHz Matlab done, Readme Updated
    [Filters_PWM1kHz.SchDoc, Filters_PWM60Hz.SchDoc, Signal_Generator.PcbDoc]
2026-07-04 60HzPWM unfiltered signal matlab analysis
    [PWM60Hz_unfiltered.csv]
2026-07-04 Unfiltered 1kHz PWM oscilloscope and fft analysis
2026-07-17 Update 60Hz and 1kHz reconstruction filters BreadBoard validation
2026-07-22 ReadMe, PWM data analysis partial
    [PWM60Hz_unfiltered_old.csv]
2026-07-24 Altium grid fixes
    [Differential_Signal_Generator.SchDoc, Filters_PWM1kHz.SchDoc, Filters_PWM60Hz.SchDoc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]
2026-07-25 ReadMe, only PCB sections to go!
2026-07-26 PCBs review before Order
    [Differential_Signal_Generator.SchDoc, Filters_PWM1kHz.SchDoc, Filters_PWM60Hz.SchDoc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]
2026-07-27 Updated gerbers
    [Instrumentation-Amplifier.GBL, Instrumentation-Amplifier.GBO, Instrumentation-Amplifier.GBS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]
2026-07-28 Active BOM, readme
    [instrumentation-amplifier.PrjPcb, instrumentation-amplifier.SchDoc]
2026-07-29 BOM, order done
    [BOM.xlsx]
2026-08-08 PCB soldering mods
    [BOM.xlsx, Filters_PWM60Hz.SchDoc, Generator_main.SchDoc]
